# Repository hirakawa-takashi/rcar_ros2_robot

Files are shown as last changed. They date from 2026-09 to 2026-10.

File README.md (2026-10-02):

# rcar_ros2_robot (AI-CAR)

Raspberry Pi 5 + ROS2 Jazzy で動作するメカナム4輪自律走行ロボット AI-CAR のワークスペース。

## パッケージ

| パッケージ | 内容 |
|---|---|
| `ai_car_description` | URDF/Xacro モデル、表示用 Launch、RViz2 設定 |
| `ai_car_web` | FastAPI による Web ダッシュボード（テレメトリ表示・手動操作・システム監視） |

## ビルド

```bash
source /opt/ros/jazzy/setup.bash
cd ~/AI-CAR_ws
colcon build --symlink-install
source install/setup.bash
```

## 実行

ロボットモデルの表示（RViz2 は開発PC側で起動する想定）:

```bash
ros2 launch ai_car_description view_robot.launch.py          # robot_state_publisher + joint_state_publisher
ros2 launch ai_car_description view_robot.launch.py use_rviz:=true use_gui:=true
```

Web ダッシュボード:

```bash
ros2 launch ai_car_web dashboard.launch.py
# システム監視ノードを止める場合: use_system_monitor:=false
# ブラウザで http://<ラズパイのIP>:8080
```

起動時の自動起動（systemd）:

```bash
sudo ~/AI-CAR_ws/systemd/install_service.sh   # /etc/systemd/system/ai-car-dashboard.service を登録して起動
systemctl status ai-car-dashboard.service
sudo systemctl disable --now ai-car-dashboard.service   # 手動起動に戻す場合
```

サービスは `Restart=always`（5秒間隔）で、USB デバイスの認識を待つため起動を10秒遅延する。カメラ、LiDAR、IMU のノードは launch 側で `respawn` する。

CPU ファンの作動温度（既定 50/60/67.5/75℃）を前倒しして高温になりにくくする:

```bash
sudo cp ~/AI-CAR_ws/systemd/ai-car-fan.service /etc/systemd/system/
sudo systemctl enable --now ai-car-fan.service   # 45/50/55/62℃ を設定（起動ごとに再適用）
# 温度を変えたい場合は Environment=FAN_TRIP_TEMPS="..." をサービスに追加
```

設定値は `scripts/set_fan_curve.sh` が `thermal_zone0` の active トリップへ書き込む。ファン回転数と段階はダッシュボードの CPU カードに表示される。

## インターフェース

`dashboard_node`

- Publish: `/cmd_vel` (`geometry_msgs/Twist`)、`~/status` (`std_msgs/String`)
- Subscribe: `/scan` (`sensor_msgs/LaserScan`)、`/imu/data` (`sensor_msgs/Imu`)、`/odom` (`nav_msgs/Odometry`)、`/system_status` (`std_msgs/String`)、`/camera/image_raw/compressed` (`sensor_msgs/CompressedImage`)
- HTTP: `GET /`、`GET /api/status`、`GET /api/architecture`、`GET /api/dev_diary`、`POST /api/cmd_vel`、`POST /api/stop`、`GET /api/camera/snapshot`、`GET /api/camera/stream`（MJPEG）、WebSocket `/ws`
- パラメータ: `src/ai_car_web/config/dashboard.yaml`

操作コマンドは -1.0〜1.0 の正規化値で受け取り、`max_linear_speed` / `max_angular_speed` にスケールされる。
`cmd_timeout`（既定 0.7 秒）の間に新しい指令が来ない場合は自動的に停止する。
画面上部の「プロジェクト説明」ボタンから、`architecture.yaml` に基づく構成・安全機構・API・開発状況の7タブを確認できる。
`dashboard_node.api_token` または環境変数 `AI_CAR_API_TOKEN` を設定すると、POST `/api/*` に
`X-API-Token`（または Bearer）ヘッダーが必要になる。UI は `http://<PI_IP>:8080/?token=...` を
一度開くとトークンを localStorage に保存する。

`system_monitor_node`

- Publish: `/system_status` (`std_msgs/String`, JSON, 既定 1Hz)
- 内容: CPU 使用率（全体・コア別）・クロック・温度・ロードアベレージ、メモリ/Swap/ディスク、PMIC レール別の電圧・電流・電力と合計消費電力、スロットリング状態、AI HAT+ (Hailo-8) 検出状態
- パラメータ: `publish_rate` / `topic` / `enable_pmic` / `enable_hailo`
- 依存: `python3-psutil`、`vcgencmd`（Raspberry Pi）、`lspci`
- AI HAT+ の情報は `/dev/hailo0`（`hailo_pci` ドライバ）と `hailortcli` の有無に応じて段階的に表示する。ドライバ未導入時は PCIe 検出状態のみ。
- AI HAT+ の温度は HailoRT の C API `hailo_get_chip_temperature()` を ctypes で直接呼び出して取得する（ts0/ts1 の平均。`hailortcli` 4.24 に温度サブコマンドは無い）。
- NPU 使用率と消費電力は取得・表示しない（使用率は推論アプリを `HAILO_MONITOR=1` で起動している間だけ `hailortcli monitor` で参照できる）。
- AI HAT+ の電力は取得できない。`hailortcli measure-power` は `HAILO_UNSUPPORTED_OPCODE`（ボードに電流監視 DVM 非搭載）、`query_health_stats()` / `query_performance_stats()` は HAILO8 アーキテクチャ非対応。`hatctl` は Raspberry Pi OS / 他ベンダ向けで Ubuntu には存在せず、Hailo 専用の hwmon デバイスも無い。PMIC にも HAT 専用レールはなく（AI HAT+ は PCIe コネクタの 5V から給電）、単体の消費電力を測るには INA219/INA3221 などの外付け I2C 電流センサを配線に挿入する必要がある。
- ダッシュボードの AI HAT+ カードは温度（横バーグラフ）・状態・デバイス情報（アーキテクチャ / FW / ドライバ / PCIe アドレス）を表示する（NPU 使用率と消費電力は表示しない）。

## TM1637 4桁7セグメントLED のセットアップ（旧表示器）

`seg_display_node` は TM1637 モジュールを bit-bang 駆動し、`/display_state`
（`std_msgs/String`）へ現在の状態コードを publish する。

| TM1637 | Raspberry Pi 5 |
|---|---|
| VCC | 17（3V3） |
| GND | 20（GND） |
| CLK | 16（GPIO23） |
| DIO | 18（GPIO24） |

```bash
sudo apt install python3-libgpiod
sudo usermod -aG dialout super
# 再ログイン、またはサービスを再起動
```

GPIO チップは `pinctrl-rp1` のラベルから自動検出する（通常は `gpiochip4`）。
`dashboard.launch.py` の `use_seg_display`（既定 `true`）で起動し、
無効化する場合は `use_seg_display:=false` を指定する。

表示コード:

| コード | 意味 |
|---|---|
| `boot` | 起動後30秒以内でシステム状態未受信 |
| `rdy ` | 待機中 |
| `HAnd` | 手動操作中 |
| `ObSt` | 障害物停止 |
| `SLo ` | 減速 |
| `LoU ` | 低電圧 |
| `Err ` | システム状態未受信・タイムアウト |

## IMU (GY-BNO055) のセットアップ

`imu_node` は GY-BNO055（I2C バス1、ADRピンHigh、アドレス `0x29`）を読み取り、
`/imu/data`（`sensor_msgs/Imu`）へ publish する。I2C のアクセス権を追加して再ログインする。

```bash
sudo usermod -aG i2c super
# 再ログイン、またはサービスを再起動
i2cdetect -y 1    # 0x29 が表示されることを確認
```

`dashboard.launch.py` の `use_imu`（既定 `true`）で起動し、無効化する場合は
`use_imu:=false` を指定する。

## 落下防止センサー (VL53L1X ×2) のセットアップ

`cliff_node` は前後バンパーの Dovhmoh VL53L1X（真下から進行方向へ 45° 前傾）で床までの距離を測り、
段差の判定を `/cliff_status`（`std_msgs/String`、JSON、20 Hz）へ publish する。
測った距離が `cliff_distance_m`（既定 0.15 m。平らな床は約 0.095 m）を超えるか、床が見えない状態が
`confirm_count` 回続くと段差とする。`drive_mode_node` は前が段差なら前進、後ろが段差なら後退を止め、
自動運転は停止モードにする。

現在は未配線で、`cliff_node.wired: false` の間は I2C / GPIO に触らず「未配線」だけを配信する
（ダッシュボードの「落下防止センサー」カードに表示）。予定のピン割り付けは `gpio_pins.yaml`（配線色は未定）。

| 信号 | 前（0x30） | 後（0x31） |
| --- | --- | --- |
| VIN 3V3 | pin 1（IMU と分岐） | pin 17 |
| GND | pin 14 | pin 25 |
| SDA / SCL | pin 3 / 5（I2C バス 1 共有） | pin 3 / 5 |
| XSHUT | pin 11（GPIO17） | pin 13（GPIO27） |

VL53L1X の初期アドレス 0x29 は BNO055 と同じなので、`cliff_node` が XSHUT を 1 台ずつ上げ、
起動直後に 0x30 / 0x31 へ変える。モジュールの XSHUT は基板上で引き上げられていることが多く、
配線したのに `cliff_node` が動いていないと 0x29 で BNO055 とぶつかる。配線したら
`dashboard.yaml` の `cliff_node.wired` を `true` にしてサービスを再起動し、`i2cdetect -y 1` で
0x29（BNO055）・0x30・0x31・0x60（Motor HAT）が見えることを確かめる。
`dashboard.launch.py` の `use_cliff`（既定 `true`）で起動する。

## カメラ (IMX708 / Camera Module v3) のセットアップ（Ubuntu 24.04）

ダッシュボードは `/camera/image_raw/compressed` を購読し、`/api/camera/stream` で MJPEG 配信する。カメラノードは `camera_ros`（libcamera）を使用し、`dashboard.launch.py` の `use_camera`（既定 true）で起動する。

Ubuntu 24.04 の libcamera 0.7.2 は raspi カーネル 6.8 のメディアエンティティ名（`rp1-cfe-fe_image0` などアンダースコア形式）と一致せず `no cameras available` となるため、Raspberry Pi 版 libcamera / libpisp を `~/opt/rpicam` に導入する。

```bash
sudo apt install -y ros-jazzy-camera-ros
sudo apt install -y meson ninja-build pkg-config python3-jinja2 python3-yaml python3-ply \
  libyaml-dev libudev-dev libevent-dev libdrm-dev libjpeg-dev libtiff-dev libpng-dev \
  libssl-dev libgnutls28-dev libboost-dev libglib2.0-dev libgstreamer-plugins-base1.0-dev
# 開発用パッケージが解決できない場合は /etc/apt/sources.list.d/ubuntu.sources に noble-updates を追加する

git clone https://github.com/raspberrypi/libpisp.git ~/libpisp
cd ~/libpisp && meson setup build --prefix=$HOME/opt/rpicam && ninja -C build install

git clone https://github.com/raspberrypi/libcamera.git ~/libcamera
cd ~/libcamera
PKG_CONFIG_PATH=$HOME/opt/rpicam/lib/$(uname -m)-linux-gnu/pkgconfig \
  meson setup build --prefix=$HOME/opt/rpicam \
  -Dpipelines=rpi/pisp,rpi/vc4 -Dipas=rpi/pisp,rpi/vc4 \
  -Dv4l2=false -Dgstreamer=disabled -Dtest=false -Dlc-compliance=disabled \
  -Dcam=enabled -Dqcam=disabled -Ddocumentation=disabled -Dpycamera=disabled \
  -Dcpp_args=-I$HOME/opt/rpicam/include
ninja -C build install

# 確認
LD_LIBRARY_PATH=$HOME/opt/rpicam/lib/$(uname -m)-linux-gnu $HOME/opt/rpicam/bin/cam -l
```

`dashboard.launch.py` は `~/opt/rpicam` があればカメラノードの `LD_LIBRARY_PATH` に自動で追加する（apt 版 `camera_ros` をそのまま利用できる）。

## AI HAT+ (Hailo-8) のセットアップ（Ubuntu 24.04）

`hailo-all` は Raspberry Pi OS 専用のため Ubuntu では使えない。ドライバと HailoRT をソースから導入する。

```bash
sudo apt-get install -y linux-headers-$(uname -r) build-essential cmake git
git clone https://github.com/hailo-ai/hailort-drivers.git
cd hailort-drivers && git checkout v4.24.0          # v5 系は Hailo-10 専用で Hailo-8 (1e60:2864) 非対応
cd linux/pcie && make all && sudo make install
cd ~/hailort-drivers && ./download_firmware.sh
sudo mkdir -p /lib/firmware/hailo
sudo cp hailo8_fw*.bin /lib/firmware/hailo/hailo8_fw.bin
sudo cp linux/pcie/51-hailo-udev.rules /etc/udev/rules.d/
sudo depmod -a && sudo udevadm control --reload-rules && sudo udevadm trigger
sudo reboot

# 再起動後に HailoRT（ドライバと同じ 4.24.0）をビルド
git clone --depth 1 --branch v4.24.0 https://github.com/hailo-ai/hailort.git
cd hailort && cmake -S . -B build -DCMAKE_BUILD_TYPE=Release -DHAILO_BUILD_PYBIND=OFF
cmake --build build --config release -j2
sudo cmake --install build && sudo ldconfig
hailortcli fw-control identify
```

### Python バインディング（`perception_node` の推論に必要）

```bash
cmake -S ~/hailort/hailort/libhailort/bindings/python/src -B ~/pyhailort_build \
      -DPYBIND11_PYTHON_VERSION=3.12 -DCMAKE_BUILD_TYPE=Release
cmake --build ~/pyhailort_build -j4
cp ~/pyhailort_build/_pyhailort*.so \
   ~/hailort/hailort/libhailort/bindings/python/platform/hailo_platform/pyhailort/
pip3 install --user --break-system-packages \
   ~/hailort/hailort/libhailort/bindings/python/platform
python3 -c "from hailo_platform import VDevice; print('ok')"
```

### 物体検出モデル

```bash
mkdir -p ~/AI-CAR_ws/models
curl -L -o ~/AI-CAR_ws/models/yolov8m.hef \
  https://hailo-model-zoo.s3.eu-west-2.amazonaws.com/ModelZoo/Compiled/v2.16.0/hailo8/yolov8m.hef
```

標準設定は YOLOv8m で、パスは `config/dashboard.yaml` の `perception_node.hef_path` で指定する。YOLOv8s / YOLOv8n を使う場合は `hef_path` をそれぞれ `~/AI-CAR_ws/models/yolov8s.hef` / `~/AI-CAR_ws/models/yolov8n.hef` に変更する（未設定なら LiDAR 判定のみで動作）。

## 依存

```bash
sudo apt install -y ros-jazzy-robot-state-publisher ros-jazzy-joint-state-publisher ros-jazzy-xacro
# SLAM（地図と自己位置、use_slam:=true）を使うとき
# 地図の保存（/slam_toolbox/save_map）は nav2_map_server の map_saver_cli を使う
sudo apt install -y ros-jazzy-slam-toolbox ros-jazzy-nav2-map-server
sudo apt install -y python3-psutil
pip3 install fastapi uvicorn
# WebSocket 配信（未導入なら /api/status の 250ms ポーリングへ自動フォールバック）。
# apt の python3-websockets 10.4 は uvicorn が要求する API を持たないため使わない。
pip3 install --user --break-system-packages "websockets>=13"
```

映像の滑らかさは `config/dashboard.yaml` で調整する。既定は `camera` の `width: 960` /
`height: 540` / `jpeg_quality: 80`（`FrameDurationLimits` により約 30fps。以前の 1280×720 は camera_node の CPU が約 50% になるため縮小）、`dashboard_node.camera_stream_rate: 30.0`、
`perception_node.inference_rate: 15.0`、`dashboard_node.telemetry_rate: 10.0`、`dashboard_node.scan_max_points: 720`、
`autonomy_node.publish_rate: 10.0`、`joy_teleop_node.publish_rate: 10.0`、`imu_node.publish_rate: 20.0` に設定している。
帯域や CPU が厳しい場合は解像度か `jpeg_quality` を下げる。

## ドキュメント

- 開発方針: `PROJECT_RULES.md`
- 実装状況: `PROJECT_STATUS.md`
- ハードウェア構成: `HARDWARE_BOM.md`
- 変更履歴: `CHANGELOG.md`

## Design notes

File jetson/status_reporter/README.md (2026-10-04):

# Jetson の状態を AI-CAR のダッシュボードに出す

Jetson Orin Nano Super の温度・使用率・メモリ・電力・AI の部品（声の AI・物体検出）・
セキュリティ更新の状況を、1 秒ごとに AI-CAR へ送ります。ダッシュボードの
「Jetson Orin Nano Super」カードに出ます。

```
Jetson  /proc・/sys・systemctl・HTTP（whisper 8178 / Ollama 11434 / Kokoro 8880）
        → POST /api/jetson/status（API トークン）→ AI-CAR の dashboard_node → /api/status の jetson_host
```

5 秒以上届かないと、カードは「未接続」になります。表示だけで、AI-CAR の速度には使いません。

## 送るもの
- 温度（CPU・GPU・Tj）、CPU / GPU の使用率とクロック、ファン
- メモリ・スワップ・ディスク、ボード全体の入力電圧と消費電力（INA3221 の `VDD_IN`）、電源モード（`nvpmodel -q`）
- AI の部品が動いているか: `whisper-server`（声→文字。`whisper-server.service` の `-m` から仕組みの名前 `stt_engine`、例: whisper.cpp small（GPU））、`ollama`（会話の AI、読み込み中のモデルと、その大きさ・GPU に載っている量）、
  Kokoro（文字→声、Docker。`/openapi.json` の題名と版から `tts_engine`、例: Kokoro TTS 1.0.0）、`jetson-owl`（NanoOWL の物体検出）
- 更新: 残りの更新とセキュリティ更新の数（`apt-check`、重いので 1 時間に 1 回と、ボタンの更新のあと）、再起動が必要か、
  最後に自動更新（unattended-upgrades）が動いた時刻。残りの更新の数には、NVIDIA の部品（JetPack: `nvidia-`・`cuda-`・
  `libcudnn`・`libnvinfer`・`tensorrt`）を入れない（その数は `updates_held`）。ボタンの更新が動いているかと、前回の結果
- IP アドレス（Tailscale・Wi-Fi など。lo・Docker・USB の `l4tbr0` は出さない。30 秒ごとに調べる）、再起動ボタンが使えるか（`sudo -n -l`）

## ファイル
- `jetson_status.py`: 本体。標準ライブラリだけで動く（Jetson の `/usr/bin/python3`）
- `jetson-status.service`: Jetson の systemd サービス（ユーザー `jetson` で動かす）
- `jetson-upgrade.sh`・`jetson-upgrade.service`・`jetson-upgrade.sudoers`: ダッシュボードの「Jetson を更新」ボタン用

## 入れ方（Jetson、JetPack 6.2 / L4T 36.4.3 で確認）
```bash
# このフォルダを ~/status_reporter にコピーする
sudo install -m 600 /dev/null /etc/jetson-status.env
sudoedit /etc/jetson-status.env   # 次の 2 行を書く（jetson-owl と同じ値）
#   AI_CAR_URL=http://100.70.35.31:8080
#   AI_CAR_API_TOKEN=<AI-CAR の dashboard_node の API トークン>
sudo cp ~/status_reporter/jetson-status.service /etc/systemd/system/
sudo systemctl daemon-reload
sudo systemctl enable --now jetson-status.service
journalctl -u jetson-status -f
```

## ダッシュボードの「再起動」「電源を切る」ボタン
Jetson カードの「Jetson を再起動」を押すと、AI-CAR は次に状態が届いたときの返事に `"reboot": true` を入れます。
`jetson_status.py` はそれを見て `sudo -n systemctl reboot` を実行します。「Jetson の電源を切る」は `"poweroff": true` で、`sudo -n systemctl poweroff` を実行します（入れ直すのは本体の電源ボタンか電源のつなぎ直し）。パスワードなしで再起動と電源を切ることだけを許す設定が要ります:
```bash
sudo visudo -cf ~/status_reporter/jetson-reboot.sudoers
sudo install -m 440 ~/status_reporter/jetson-reboot.sudoers /etc/sudoers.d/jetson-reboot
```
入っていないときはボタンを押しても「jetson-reboot.sudoers が入っていません」（電源は「… に poweroff が入っていません」）と出て、何もしません。

## ダッシュボードの「Jetson を更新」ボタン
自動の更新（unattended-upgrades）はセキュリティ更新だけを入れます。ほかの更新は、ボタンを押したときだけ入れます。
押すと、AI-CAR は次の返事に `"upgrade": true` を入れ、`jetson_status.py` が `sudo -n systemctl start --no-block jetson-upgrade.service` を実行します。
`jetson-upgrade.sh`（root）は `apt-get update` のあと、NVIDIA の部品を除いて `apt-get install --only-upgrade` します。
先に試しに動かして（`apt-get -s`）、NVIDIA の部品が変わるか、消える部品があるときは、更新せずに失敗にします。
動いているあいだはカードに「更新中 45 %」のように進み具合が出ます（`jetson-upgrade.sh` が `/run/jetson-upgrade.progress` に書く。ダウンロードが 0〜30 %、インストールが 30〜100 %）。終わると「前回は成功」か「前回は失敗」と出ます。記録は `journalctl -u jetson-upgrade` で見られます。
```bash
sudo install -m 755 ~/status_reporter/jetson-upgrade.sh /usr/local/sbin/jetson-upgrade
sudo cp ~/status_reporter/jetson-upgrade.service /etc/systemd/system/
sudo systemctl daemon-reload
sudo visudo -cf ~/status_reporter/jetson-upgrade.sudoers
sudo install -m 440 ~/status_reporter/jetson-upgrade.sudoers /etc/sudoers.d/jetson-upgrade
sudo systemctl restart jetson-status.service
```

1 回だけ集めて表示するとき（AI-CAR には送らない）:
```bash
python3 ~/status_reporter/jetson_status.py --once
```

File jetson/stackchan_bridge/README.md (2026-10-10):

# スタックちゃんを Jetson の会話の AI につなぐ（stackchan_bridge）

M5Stack の純正ファームウェア（StackChan 1.5.1、中の会話は XiaoZhi）の AI Agent を、
ネットの向こうの XiaoZhi のサーバーではなく、家の Jetson の会話の AI につなぎます。
表情・首振り・画面・タッチは純正のままです。AI-CAR の走行・安全停止には何も送りません。

```
スタックちゃん ──HTTP :8003 /xiaozhi/ota/──▶ stackchan_bridge（WebSocket の行き先だけ返す。新しい版は返さない）
             ──WebSocket :8000 /xiaozhi/v1/─▶ 声（Opus 16 kHz）→ 音の大きさで区切る
                                              → whisper-server :8178（声→文字）
                                              → Ollama :11434 qwen2.5:3b（返事、1 文ずつ）
                                              → Kokoro :8880 jf_alpha + sox pitch 300・norm -1 dB（文字→声）
             ◀── Opus 24 kHz・60 ms ──────────┘  stt / llm（表情）/ tts の JSON も送る
```

- 2026/10 の実機: 聞き取り 約 0.3〜0.7 秒、話し終わってから声が出るまで 約 1.6〜2.8 秒。メモリ 約 37 MB
- 返事の声: Kokoro のままだといちばん大きい所が上限の約 4 割（-7 dB）で小さかったので、文ごとに -1 dB にそろえる（`--peak-db`）
- 声の区切り: まわりの音の 3 倍（最低 RMS 300）より大きいと話し始め、0.8 秒静かなら話し終わり（`--ratio`・`--min-level`・`--end-silence`）。
  「(音楽)」のような文字だけの聞き取りは捨てる
- whisper の聞き取り: 毎回 `no_context=true` を送る（前の聞き取りを手がかりにすると、一度まちがえたあと、どの声も「(スタックちゃん)」のような決まった言葉になる）。5 分ごとに Kokoro の「スタックちゃん」（呼びかけが出るはず）と「今日の天気はどうですか」（出ないはず）を聞き取らせ、ちがえば `pkill -KILL -x whisper-server` で止める（`Restart=on-failure` で起動し直る）
- 呼びかけ待ちの首ふり: スタックちゃんはいつも聞いている（listening）ので、純正の待ち受けの首ふりは動かない。bridge が 5〜10 秒ごとに `self.robot.set_head_angles` で首を動かす（純正の 4 種類をまねる）。動かしてから 1.2 秒は新しい声の区切りを始めない。居眠り中・会話中・撮影中は動かさない
- 会話は 3 往復まで覚える（WebSocket が切れると忘れる）。今の日時をシステムの指示に入れる
- `GET :8003/status`: つながり（`connected`）・今の様子（`state`: `listening` / `thinking` / `speaking` / `idle`）・最後の会話（`last`: 聞き取り・返事・かかった秒）・本体（`device`: MAC・IP・版）・会話の数（`turns`）を JSON で返す。AI-CAR のダッシュボードのスタックちゃんのカードが `GET /api/stackchan/status` 経由で 2 秒ごとに取る
- カメラ: つながると MCP の `initialize` で写真の送り先（`http://<Jetson>:8003/vision`）を教え、`tools/list` に `self.camera.take_photo` があれば `camera: true`。`POST :8003/photo` でその道具を呼ぶと、スタックちゃんが 320×240 の JPEG（約 12 KB）を `/vision` へ送り、`GET :8003/photo.jpg` でいちばん新しい 1 枚を返す（`photo_at` は撮った時刻）。ファイルには保存しない。撮るたびにスタックちゃんでシャッターの音が鳴る。ダッシュボードの「写真を撮る」が `POST /api/stackchan/photo` 経由で呼ぶ
- 認証はしない（`token` は空）。家の LAN・Tailscale の中だけで使う

## Jetson に入れる

```bash
mkdir -p ~/stackchan_bridge
cp stackchan_bridge.py ~/stackchan_bridge/
pip3 install --user websockets==13.1 opuslib==3.0.1   # libopus0 と sox も要る
sudo install -m 644 jetson-stackchan.service /etc/systemd/system/
sudo systemctl daemon-reload
sudo systemctl enable --now jetson-stackchan.service
journalctl -u jetson-stackchan -f    # 聞き取り・返事・かかった秒数が出る
```

## パソコンで聞き取りと返事（WSL の Ubuntu、RTX 4080 SUPER）

パソコンが動いているあいだは、聞き取り（whisper large-v3）と返事（Ollama qwen2.5:14b）をパソコンでする。
文字→声（Kokoro）・呼びかけの見分け・カメラ・見守りは Jetson のまま。

- bridge が 10 秒ごとに `http://<パソコン>:8178/` と `:11434/api/tags` を見て（2 秒で時間切れ）、どちらも返事をして
  `--pc-model` があれば、モデルを読み込ませてからパソコンを使う。聞き取り（10 秒）・返事（10 秒）でつながらなければ、
  その回から Jetson（whisper small・qwen2.5:3b）にもどす。返事の途中で切れたときは、その返事はやめる
- 行き先は `--pc-host`（既定は環境変数 `AI_PC_HOST`、なければ Tailscale の taka3-wsl `100.86.172.21`）。空でパソコンを使わない
- 使っているほうは `GET :8003/status` の `engines` に出る（「（パソコン）」がつく）。`backend` は `want`（選んだ所 `jetson` / `pc`）・`active`（今使っている所）・`error`（パソコンにつながらない理由）
- パソコンの状態（ダッシュボードでパソコンを選んだときの Jetson のカード）: `pc/pc_status.py` を `/home/super/ai/` に置き、`pc/pc-status.service` を入れる（`/etc/pc-status.env` に `AI_CAR_API_TOKEN=...`）。1 秒ごとに `POST /api/mypc/status`（jetson-status と同じ形 ＋ `gpu_name`・`gpu_driver`）
- 声でも切りかえる（ローカルのときの会話モードで）: 「ミニコン / ジェットソン」→ `jetson`、「パソコン / PC」のあとに「にして」など（ネット / ローカルと同じ言い方）。ネット / ローカルとは別で、どちらの組み合わせでも使える。ネットのあいだの言葉は XiaoZhi が聞くので、先に「ローカルにして」
- 切り替え: `POST :8003/backend?to=jetson|pc`（ダッシュボードの Jetson のカードの 1 行目のミニコン / パソコンボタンが `POST /api/stackchan/backend` 経由で呼ぶ）。`backend.txt` に書いて、起動し直してもそのまま。`jetson` ならパソコンを見ない。`pc` にするとすぐパソコンを見て、動いていれば使う（つながらないあいだは Jetson）
- whisper の見回り（5 分ごと）は Jetson の whisper-server だけを試す
- 文字→声: パソコンを使っているあいだは、パソコンの VOICEVOX ENGINE（CPU、`:50021`）の `--pc-speaker`（既定 3 = ずんだもん ノーマル）。高さはそのまま（Kokoro だけ `--pitch` で上げる）。パソコンを見るときに `POST /initialize_speaker` で読み込ませ、だめならその回から Kokoro。2026/10 の実機（ミニコンから）: 「こんにちは。」0.27 秒、26 文字の文 0.75 秒。家の中だけで使う（外に出すときは「VOICEVOX:ずんだもん」と書く決まり）
- 2026/10/10 の実機（Jetson から同じ声 4 つ）: 聞き取り Jetson 0.53〜0.74 秒 → パソコン 0.29〜0.44 秒（Tailscale の中継込み）。
  返事は Jetson qwen2.5:3b 15〜17 文字片/秒 → パソコン qwen2.5:14b 約 62 文字片/秒（読み込みは最初の 1 回 約 31 秒）。
  GPU のメモリは whisper large-v3 と 14b で 16 GB のうち約 13.9 GB

パソコンに入れる（WSL 3.0.1 の Ubuntu 26.04、ユーザー `super`、Tailscale と openssh-server 入り）:

```bash
sudo apt install -y build-essential cmake git
# CUDA（WSL 用。Windows の NVIDIA ドライバーはそのまま）
curl -fsSLO https://developer.download.nvidia.com/compute/cuda/repos/wsl-ubuntu/x86_64/cuda-keyring_1.1-1_all.deb
sudo dpkg -i cuda-keyring_1.1-1_all.deb && sudo apt update && sudo apt install -y cuda-toolkit-13-3
mkdir -p ~/ai && cd ~/ai && git clone --depth 1 https://github.com/ggml-org/whisper.cpp && cd whisper.cpp
curl -fL -o models/ggml-large-v3.bin https://huggingface.co/ggerganov/whisper.cpp/resolve/main/ggml-large-v3.bin
PATH=/usr/local/cuda/bin:$PATH cmake -B build -DGGML_CUDA=1 -DCMAKE_CUDA_ARCHITECTURES=89 -DCMAKE_BUILD_TYPE=Release
cmake --build build -j 24 --target whisper-server
sudo install -m 644 pc/whisper-server.service /etc/systemd/system/   # このフォルダの pc/
curl -fsSL https://ollama.com/install.sh | sh
sudo install -D -m 644 pc/ollama-override.conf /etc/systemd/system/ollama.service.d/override.conf
sudo systemctl daemon-reload && sudo systemctl enable --now whisper-server && sudo systemctl restart ollama
ollama pull qwen2.5:14b
# VOICEVOX ENGINE 0.25.2（linux-cpu-x64）を https://github.com/VOICEVOX/voicevox_engine/releases から ~/ai/voicevox に展開
sudo install -m 644 pc/voicevox.service /etc/systemd/system/ && sudo systemctl daemon-reload && sudo systemctl enable --now voicevox
# CPU 温度: Windows に LibreHardwareMonitor 0.9.6 を置き、管理者で 1 回起動して Options の「Run On Windows Startup」「Start Minimized」「Remote Web Server → Run」を入れる
#   （設定ファイルでは runWebServerMenuItem=true。pc_status.py は Windows の PowerShell から http://localhost:8085/data.json の CPU Package を読む）
```

WSL は PowerShell の画面を閉じるとしばらくして止まるので、`pc/wsl-ubuntu-keepalive.vbs` を Windows の
スタートアップ（`%APPDATA%\Microsoft\Windows\Start Menu\Programs\Startup`）に置き、ログインしたら
`wsl.exe -d Ubuntu --exec /bin/sleep infinity` を見えないまま動かしておく（消せば元にもどる）。

## スタックちゃんのファームウェア

公式 https://github.com/m5stack/StackChan の `firmware`（ESP-IDF v5.5.4）に、ここの 4 つを足してビルドします。

| ファイル | 置く所 | 中身 |
| --- | --- | --- |
| `firmware/sdkconfig.defaults.local` | `StackChan/firmware/` | `CONFIG_OTA_URL` を Jetson（`http://192.168.11.23:8003/xiaozhi/ota/`）にする |
| `firmware/xiaozhi-no-auto-upgrade.patch` | `StackChan/firmware/xiaozhi-esp32/` で `git apply` | AI Agent を開くたびの自動更新（`UpgradeFirmware`）をやめ、ログだけ出す（純正の版にもどらないように） |
| `firmware/xiaozhi-auto-reopen.patch` | `StackChan/firmware/xiaozhi-esp32/` で `git apply` | 会話が切れたら（画面をさわって止めたとき以外）、自分でつなぎ直す（3 秒後、だめなら 6・12…最大 60 秒ごと。つなぎ直しの失敗ではエラーの音を出さない）。AI Agent を開いたときも 2 秒後に自分でつなぐ（下の「呼びかけ」） |
| `firmware/stackchan-camera-stream.patch` | `StackChan/firmware/` で `git apply` | カメラの映像を OTA と同じ所の `/camera/frame` へ送り続ける（下の「カメラの映像」） |
| `firmware/stackchan-face-color.patch` | `StackChan/firmware/` で `git apply` | 顔（目と口）の色を変える MCP の道具 `self.robot.set_face_color`（`color`: 0xRRGGBB）。user only なので、ネットの AI からは見えない（下の「ネットとローカルの切り替え」） |
| `firmware/xiaozhi-fallback-pc.patch` | `StackChan/firmware/xiaozhi-esp32/` で `git apply`（auto-reopen のあと） | ミニコンが答えないとき、パソコン（`AICAR_FALLBACK_HOST` 192.168.11.7、同じ 8000・8003 番）につなぐ。WebSocket は毎回ミニコンを先に試し、だめならパソコン。起動のときの OTA も、失敗するたびにミニコンとパソコンを入れかえて聞く（下の「ミニコンが落ちたとき」） |
| `firmware/stackchan-camera-follow-server.patch` | `StackChan/firmware/` で `git apply`（camera-stream のあと） | カメラの映像・撮影の写真を、今つないでいる受け口（ミニコンかパソコン）へ送る |
| `firmware/stackchan-countdown-shot.patch` | `StackChan/firmware/` で `git apply`（camera-stream のあと） | 「撮影して」の MCP の道具 `self.camera.countdown_photo`（`seconds`: 1〜9）。正面を向き、画面にカメラと数字を出して数え、撮って `/camera/shot` へ送る（下の「撮影と名前の登録」） |

```bash
cd StackChan/firmware
python3 ./fetch_repos.py                 # 依存の取得と公式のパッチ
cp <このフォルダ>/firmware/sdkconfig.defaults.local .
git -C xiaozhi-esp32 apply <このフォルダ>/firmware/xiaozhi-no-auto-upgrade.patch
git -C xiaozhi-esp32 apply <このフォルダ>/firmware/xiaozhi-auto-reopen.patch
git apply <このフォルダ>/firmware/stackchan-camera-stream.patch
git apply <このフォルダ>/firmware/stackchan-face-color.patch
git apply <このフォルダ>/firmware/stackchan-countdown-shot.patch
git -C xiaozhi-esp32 apply <このフォルダ>/firmware/xiaozhi-fallback-pc.patch
git apply <このフォルダ>/firmware/stackchan-camera-follow-server.patch
. ~/esp/esp-idf-v5.5.4/export.sh
idf.py build
# Jetson の USB-A につなぐと /dev/ttyACM0。Wi-Fi の設定（NVS）は消えない
python3 esptool.py --chip esp32s3 -p /dev/ttyACM0 -b 921600 write_flash $(cat build/flash_args)
```

- 書き込むのは ota_0（0x20000）・assets（0xa00000）・otadata（0xd000）など。NVS（0x9000）の Wi-Fi の設定と、スマホのアプリの登録はそのまま
- Jetson の IP アドレスが変わるとつながらない。ルーターで固定する（2026/10: Jetson 192.168.11.23、スタックちゃん 192.168.11.8）
- スマホのアプリで変える AI の設定（声・性格）は使わなくなる。声の大きさは本体の設定の「Volume」（0〜100、最初は 70）でも変えられる

## ミニコンが落ちたとき（パソコンの控え）

パソコンでも同じ bridge を `--primary-url` つきで動かしておきます（`pc/pc-stackchan.service`、聞き取り・返事・声は
パソコンの whisper large-v3・qwen2.5:14b・VOICEVOX）。

```
スタックちゃん → ws://192.168.11.23:8000（ミニコン）… だめなら → ws://192.168.11.7:8000（Windows）
                 → portproxy → WSL の 127.0.0.1:8000（パソコンの bridge）
```

- Windows（管理者で 1 回）: `pc/stackchan-portproxy.ps1`。LAN の `192.168.11.7:8000/8003` を WSL へ通し、ファイアウォールで
  同じ LAN（LocalSubnet）からだけ入れる。パソコンの IP アドレスはルーターで固定する
- パソコンの bridge はミニコンの `GET /status` を 10 秒ごとに見る。動いていてスタックちゃんがつながっていなければ、
  ネット / ローカルと声の選択をまねる。スタックちゃんがこちらにつながっていて、ミニコンが 3 回続けて（約 30 秒）動いていて、
  呼びかけ待ち（会話中・撮影中・ネットの会話中でない）なら、こちらから切る → スタックちゃんは 3 秒後にミニコンへつなぎ直す
- パソコンの bridge では「ミニコンにして」・`POST /backend?to=jetson` は使えない（「ミニコンが止まっているあいだは、パソコンで話します。」）。
  見守り（face_id）・Kokoro・whisper の見回りは使わない。VOICEVOX が止まると声が出ない
- ダッシュボードは、ミニコンが未接続か bridge が答えないとき、パソコンの bridge（Tailscale の :8003）からスタックちゃんの様子を出す
- ミニコンが止まってから、パソコンで話せるまで: 会話が切れて 3 秒後につなぎ直し（ミニコンへの接続が失敗してから）。
  起動のときにミニコンが止まっていれば、OTA の 1 回目の失敗から 10 秒後にパソコンに聞く

```bash
# パソコン（WSL）
sudo apt install -y python3-websockets python3-numpy python3-opencv python3-opuslib sox
mkdir -p ~/ai/stackchan_bridge && cp stackchan_bridge.py ~/ai/stackchan_bridge/
sudo install -m 644 pc/pc-stackchan.service /etc/systemd/system/ && sudo systemctl daemon-reload && sudo systemctl enable --now pc-stackchan
```

## カメラの映像

`stackchan-camera-stream.patch` を入れると、AI Agent の間、スタックちゃんが会話とは別に（画面をさわらなくても）
`http://<OTA と同じ所>/camera/frame` に聞きに来ます。

```
スタックちゃん: GET  /camera/frame          → bridge: 「1」（ダッシュボードが 10 秒以内に見に来た）/「0」
                「1」なら JPEG（320×240、品質 30、シャッターの音なし）を POST /camera/frame、返事が「1」の間くり返す
                「0」なら 2 秒ごとに GET だけ（撮らない）、つながらないと 5 秒ごと
ダッシュボード: GET /api/stackchan/frame.jpg（0.25 秒ごと、ページを見ている間だけ）→ bridge GET /camera/frame.jpg
```

- 映像はいちばん新しい 1 コマだけをメモリに置きます（保存しない）。3 秒より古いと 404
- `/status` の `stream_at`（スタックちゃんが最後に聞きに来た時刻）・`frame_at`・`fps` をダッシュボードが出します。
  `stream_at` がないときは、前のとおり「写真を撮る」（MCP の `self.camera.take_photo`）だけ
- 「写真を撮る」と映像は同じカメラを使うので、ファームウェアの中で順番に使います（`frame_mutex_`）

## 撮影と名前の登録

```
「撮影して」「写真を撮って」（ローカルは whisper、ネットは XiaoZhi の stt を bridge が見る）
  → bridge「撮影します。こっちを向いてね。」→ MCP self.camera.countdown_photo {seconds: 5}
  → スタックちゃん: 首を正面（yaw 0）へ → bridge が self.robot.set_head_angles で上（pitch 30 度、--shot-pitch。数えているあいだ 1 秒ごとに送り直す）へ → 画面にカメラの映像と右上に 5〜1 の数字（1 秒ごとにピッ）
  → 0 でシャッターの音 → 撮った写真を 6 秒画面に出す → JPEG（320×240、品質 80）を POST /camera/shot
  → bridge: face_id の /api/face/recognize で顔を見る →「撮れたよ。ダッシュボードで名前を登録してね。」など
ダッシュボード: 写真の下の「名前」→「名前を登録」→ POST /api/stackchan/enroll?name= → bridge POST /enroll?name=
  → face_id の /api/face/enroll（顔が 1 つ・幅 60 px 以上・ほかの人と近すぎない）
```

- 数えるのと撮るのは、ファームウェアの映像の送り係（`cam_frame` の task）がします。MCP の返事はすぐ返り、
  会話の動き（main の task）は止めません。bridge は写真が `/camera/shot` に届くまで最大 20 秒待ちます
- ネットのときも同じです。そのときは XiaoZhi に `abort` を送り、撮り終わるまで XiaoZhi の声と文字はスタックちゃんへ流しません
- face_id の API トークンは、`jetson-stackchan.service` の `EnvironmentFile=/etc/jetson-status.env` の
  `AI_CAR_API_TOKEN` を使います。face_id の場所は `FACE_ID_URL`（既定 `http://127.0.0.1:8090`）
- 顔の見分けは、あいさつや表示だけに使います。鍵・走行・安全停止には使いません
- `/status` の `shot_tool`（ファームウェアに道具がある）・`shooting`（数えている）・`shot`（`faces`・`name`・`error`）

## 見守りとあいさつ

```
スタックちゃんの映像の送り係が 2 秒ごとに GET /camera/frame で聞きに来る
  → bridge が見守りの時刻なら「1」→ 次に 1 枚（320×240）を POST /camera/frame
  → bridge: face_id の /api/face/recognize → 登録した人がいて、30 分あいさつしていなければ
  → 「○○さん、こんにちは！」（4〜10 時 おはよう、17 時から こんばんは）
```

- 間隔は `--watch-interval`（既定 2 秒、0 で見守りをしない）。映像の 1 枚は約 4 KB で、2〜3 秒に 1 枚です。ファームウェアの書き換えはいりません
- あいさつは、スタックちゃんが会話でつながっているときだけです（つながっていないと声を出せません）。会話・撮影・ネットとの切り替えの最中もしません
- 撮影や名前の登録をした人は、そのときあいさつしたものとして数えます
- `/status` の `watch_on`・`watch`（`at`・`faces`・`names`・`error`）・`greet`（`at`・`names`）

## 呼びかけ（「スタックちゃん」、ネットもローカルも）

スタックちゃんの中の呼びかけ（WakeNet の「Hi, Stack Chan」）は英語の読み上げ声の見本と比べるので、日本語の発音ではほとんど反応しません。
そこで、ネットのときもローカルのときも Jetson が日本語の「スタックちゃん」を聞き分けます。ファームウェアの書き換えはいりません。

```
つながる（ランプが緑）→ 「呼びかけ待ち」（/status の state が waiting）。名前なしの声には返事をしない
  → 声は whisper で文字にして、「スタックちゃん」が入っているときだけ会話モードにする
     「スタックちゃん」だけ → 「はい、なあに？」（Jetson の声）→ 会話モード
     「スタックちゃん、今日は何曜日？」→ そのまま返事して会話モード
  → 会話モードのあいだは名前なしで話せる
  → 最後に話してから 30 秒（--awake-seconds）だまっていると「じゃあ、またね。」（Jetson の声）→ 呼びかけ待ちにもどる
```

- ネットのとき: 呼びかけ待ちのあいだは、声を XiaoZhi へ送らない（Jetson で文字にするだけ）。「スタックちゃん、〜」と呼ばれたら、
  その声を Opus 16 kHz にしなおして XiaoZhi へ送り、そのあとの声はそのまま流す。会話モードの時間は、XiaoZhi の聞き取り（stt）と
  話し終わり（tts stop）でのばす。XiaoZhi が話しているあいだ（歌など）は「またね」を言わない
- ネットの会話（XiaoZhi）は、呼ばれたときに開き、「じゃあ、またね。」のときに閉じる。XiaoZhi は 1 分ほど声が届かないと、自分で
  「お疲れさん！…じゃあな！」と言って切るので、呼びかけ待ちのあいだは開いておかない（呼ばれてから話し始めるまで 約 1 秒おそくなる）
- テレビの声で起きないように、呼びかけは「文の頭で名前を呼んだ」ときだけにする（`is_call`）。whisper の音の注釈（「(音楽)」「(スタックちゃん)」）がある声、名前の前が 4 文字以上ある声（「段ボール箱、スタックちゃん」）、名前のすぐあとが「の・は・が」など（「スタックちゃんの研究」）の声、whisper-server の `--prompt` をそのまま返した声（「スタックちゃん、AI-CAR。」）は呼びかけにしない。「ねえ、スタックちゃん」「スタックちゃん、〜」は呼びかけになる
- 聞き分ける言葉は `--wake-words`（正規表現。whisper の書き方のゆれ「スダックちゃん」「スタッチャン」「Stack-chan」なども入れてある）。空にすると呼びかけ待ちにせず、今までどおり何にでも返事をする
- スタックちゃんは、Jetson から 120 秒何も届かないと会話が切れたとみなすので、60 秒ごとに `{"type": "ping"}` を送る（スタックちゃんは知らない種類として記録に 1 行出すだけ）
- 呼びかけ待ちのあいだも、聞こえた声は whisper で文字にします（1 回 約 0.4〜0.5 秒）。テレビの声なども文字にするので、Jetson が少し働きます。返事はしません
- 「ネットにして」「撮影して」も、呼びかけ待ちのときは「スタックちゃん、ネットにして」のように名前を付けて言います
- 呼びかけは、スタックちゃんが Jetson につながっている（ランプが緑）ときだけ聞こえます。ランプが消えている（待ち受け）ときは声を送らないので、`xiaozhi-auto-reopen.patch` で、会話が切れたら自分でつなぎ直します（画面をさわって止めたときはつなぎ直さない）。AI Agent を開いたときも、さわらなくてもつながります。つなぎ直したときも、呼びかけ待ちから始まります
- あいさつ（見守り）・切り替えのお知らせ・画面をさわって止めたあとも、30 秒は名前なしで返事できます（そのあと「じゃあ、またね。」）

## 居眠りと画面の明るさ

- 居眠り: 「じゃあ、またね。」（つながった直後は、つながったとき）から 30 秒（`--doze-seconds`、0 で居眠りしない）たつと、
  居眠りの顔（`{"type": "llm", "emotion": "sleepy"}`、画面に Zzz）にして、首をホーム（正面・水平、MCP `self.robot.set_head_angles` の yaw 0・pitch 0）にもどす。
  呼ばれたり、あいさつしたりするときは、ふつうの顔（`neutral`）にもどす。`/status` の `dozing`
- 画面の明るさ: 見守りの映像（2〜3 秒に 1 枚）の明るさ（0〜255 の平均）の 1 分の中央値で、60 秒ごとに画面の明るさ（MCP `self.screen.set_brightness`、0〜100）を決める。
  30 未満（夜の暗い部屋）→ 10、30〜70 → 35、70 以上 → 75（もとの明るさ）。境目の近く（±8）では変えない。`/status` の `light`（映像の明るさ）・`screen`（画面の明るさ）
  - 見守りをしない（`--watch-interval 0`）と映像が来ないので、画面の明るさは変えない
  - 画面の明るさは、スタックちゃんの中に覚えさせる（電源を入れ直しても同じ明るさから始まる）。変えるのは段が変わったときだけ

## AI-CAR のようすを答える

「ラズパイの温度は？」「車の前に何かある？」「Jetson のメモリは？」のように聞くと、ダッシュボード（ラズパイの `GET /api/status`、
`--car-url`、既定は `AI_CAR_URL` か `http://100.70.35.31:8080`）の今の値で答えます。読むだけで、走行・停止・再起動のボタンは使いません。

- 渡す値: 走行モード・自動運転の動き、LiDAR の前の距離、障害物、ラズパイの CPU・温度・メモリ・ディスク・起動からの時間、
  5V の電圧・電力・電圧低下の回数、AI HAT+ の温度、更新の数、ゲームパッド、カメラ、Jetson の CPU・GPU・温度・メモリ・電力（`car_status()` で短い文にする）
- ローカルのとき: 聞き取りに「ラズパイ」「ダッシュボード」「Jetson」「車」「LiDAR」「障害物」「CPU」「メモリ」「電圧」などが入っていたら、
  その文を Ollama の system に足す（3 秒でつながらなければ「ダッシュボードにつながりません」と伝える）。ネットは使わない
- ネットのとき: MCP の道具 `self.car.status` を XiaoZhi に見せ、XiaoZhi が呼んだら bridge が同じ文を返す

## ネットとローカルの切り替え

スタックちゃんはいつも Jetson につなぎ、ネットのときは bridge がネットの XiaoZhi へ中継します（ファームウェアの行き先は変えない）。

```
「ネットにして」（Jetson の whisper が聞き取る）→ 「ネットにつなぎます」→ bridge が XiaoZhi の OTA
  （https://api.tenclass.net/xiaozhi/ota/、スタックちゃんの Device-Id・Client-Id で）に聞いて wss につなぐ
  → スタックちゃんの hello を送り、声・JSON・MCP をそのまま中継（session_id だけ入れかえる）。顔は緑（0x00FF00）
「ローカルにして」（XiaoZhi の stt を bridge が見る）→ 中継をやめる → 顔は白 →「ローカルにもどりました」
```

- 言い方: 「ネット / インターネット / クラウド / NET」か「ローカル / LOCAL」のあとに
  「モード」「にして」「に切り替えて」「に変えて」「につないで」「に戻して」。「ネットで調べて」などでは切りかわらない
- 今の行き先は `mode.txt`、スタックちゃんの最後の OTA の問い合わせ（ネットの OTA にも同じものを送る）は `device_ota.json`（どちらも bridge と同じフォルダ）に残す。bridge やスタックちゃんを起動し直しても同じ。`/status` の `mode`（`local` / `net`）
- ネットにつながらない・登録が要るときは、「ネットにつながりませんでした。ローカルで話します。」と言ってローカルのまま
- ネットの間も、カメラの映像（`/camera/frame`）は Jetson に来ます。「写真を撮る」は、XiaoZhi が写真の送り先を自分のほうに変えるので使えません（ローカルにもどると、送り先を Jetson にもどす）
- XiaoZhi が会話を切っても、スタックちゃんとの会話は切りません。次に「スタックちゃん」と呼ばれたら、つなぎ直します
- ネットの間も Jetson を通るので、Jetson が止まると会話はできません（走行・安全停止には関係ありません）

### パソコンのときの「ネット」（調べるだけ）

パソコンを選んでいて、パソコンが動いているときの「ネットにして」は、XiaoZhi につながず、会話はパソコンの qwen2.5:14b（選んだ声の話し方・性格）のままにします。顔は緑、`mode.txt` は `net`、言うことは「ネットで調べながら話します。」。

- 毎回の質問で、ミニコンが調べた結果を会話の AI のプロンプトに足す（`web_info`、いっしょに調べて 6 秒まで、間に合わない所は飛ばす、全部で 1,500 字まで）
  - はじめに、パソコンの qwen2.5:14b に質問から検索ことばを作らせる（`search_words`、例「今ネットに繋がってるから、ウクライナの首相調べて」→「ウクライナ 首相」、約 0.2〜0.5 秒）。だめなら質問の文から「今の・誰・調べて」などを除くだけ
  - いつも: Wikipedia（日本語）の上から 2 記事の、はじめの説明と右の表（`incumbent`・`incumbentsince` など。今の首相・社長がわかる。API は 1 回だけ。何回も聞くと 429）
  - いつも: DuckDuckGo の上から 4 つのページの説明、Google ニュースの検索（`news.google.com/rss/search`、5 件の見出しと日付）
  - 「天気・雨・気温・傘」など: Open-Meteo（キー不要）の今・今日・明日・あさって。場所はネットの出口の IP（ip-api.com、1 回だけ）
  - 「ニュース・話題」など: Google ニュースのトップ 5 件
- ローカルのときは「ネットは見られないので、新しいことはわからないと言う」をプロンプトに足す
- パソコンが止まっているあいだの「ネット」は、今までどおり XiaoZhi の会話（声はミニコンの Kokoro）
- 2026/10 の実機（qwen2.5:14b）: 調べる 0.4〜1.0 秒、「今の日本の総理大臣は誰？」→「高市早苗殿ですわ」（四国めたん。調べないと「岸田文雄さん」と答えていた）

### 声ごとの話し方・性格

パソコンの VOICEVOX の声を選ぶと、ローカルの会話の AI の最初の決まり（`system_prompt`）を、その声のキャラクターにします（`PC_PERSONAS`・`PERSONA_PROMPT`）。「だれ？」「誰の声？」「名前は？」には、そのキャラクターの名前で答えます（このときはネットで調べない、`SELF_ASK`）。ミニコン（Kokoro）のときは今までどおり「スタックちゃん」です。

| 声 | 名乗る名前 | 話し方 |
|---|---|---|
| ずんだもん | ずんだもん | 一人称「ボク」、文の終わりはいつも「〜のだ」「〜なのだ」。明るく元気 |
| 四国めたん | 四国めたん | 一人称「わたくし」、「〜ですわ」「〜ですの」「〜かしら」。上品 |
| 春日部つむぎ | 春日部つむぎ | 一人称「あーし」、「〜じゃん」「マジで」。人なつっこい |
| 冥鳴ひまり | 冥鳴ひまり | 一人称「わたし」、おっとりした静かな丁寧語 |
| もち子さん | もち子 | 一人称「わたし」、やさしいお姉さんの丁寧語、ほめ上手 |

返事の中のキリル・アラビア・タイ・ハングルの文字は読まずに消す（`FOREIGN_TEXT`。qwen2.5 がときどき混ぜる）。漢字ばかりで、かなが漢字の 1/4 より少なく、「，你我们么」など中国語だけの字がある文も読まない（`is_chinese`）。

## 純正にもどす

書き換える前に、純正の全部（16 MB、版 1.5.1）を Jetson の `~/stackchan_backup/stackchan_factory_16MB.bin`
（SHA-256 `7dcebeb7bfb540c758df5d1936169511d5b9ab4116ed8ccd0cdb90a96e02fbad`）にとってあります。約 4 分です。

```bash
python3 esptool.py --chip esp32s3 -p /dev/ttyACM0 -b 921600 write_flash 0x0 ~/stackchan_backup/stackchan_factory_16MB.bin
```

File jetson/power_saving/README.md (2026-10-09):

# power_saving（Jetson の省電力を切る）

Jetson が置いたままで止まる（ping は返るが SSH・AI・状態の送信が止まる）ことの対策として、省電力を切る。今は Wi-Fi だけ。SSD の 2 つ（APST・HMB）は効かなかったので、2026-10-09 にもとに戻した（`install.sh` は前に入れた分を消す）。

| 設定 | ふつう | 今 | 効き始め |
|---|---|---|---|
| SSD（MAXIO MAP1202）の APST | 0.1 秒使わないと PS3（0.75 W、起きるのに 10 ms） | ふつうのまま（10/8〜10/9 は切 `nvme_core.default_ps_max_latency_us=0`） | 次の起動 |
| SSD に Jetson のメモリを貸す（HMB） | 16 MB 貸す（SSD は自分のメモリを持たない） | ふつうのまま（10/9 は切 `nvme.max_host_mem_size_mb=0`） | 次の起動 |
| Wi-Fi（RTL8822CE）の省電力 | `wifi.powersave = 3`（オン） | `2`（切） | すぐ（Wi-Fi が数秒切れる） |

- 2026-10 の調べ: SSD は電源を入れた 20 回のうち 9 回が unsafe shutdown、読み書きのエラーは 0。Wi-Fi は 3 日 17 時間で 16 回切れていた（電波 -45 dBm）。止まった原因かどうかは、まだわかっていない（止まったときの記録は `../health_log` で取る）。
- 2026-10-09: APST を切っても、SSD を差し直しても、SSD が起動から約 52・60 分で返事をしなくなった（`/sys/fs/pstore/console-ramoops-0` に `nvme nvme0: I/O ... timeout` → `reset controller` → `Device not ready; aborting reset, CSTS=0x1`）。次の手として HMB を切った。小さなファイルの読み書きは少し遅くなる（見込み）。
- 2026-10-09: HMB を切っても、起動から 43 分・17 分で同じように止まった（ふつうに終わらず切れた回数 10 → 14）。APST・HMB はどちらも効かなかったので、もとに戻した。止まるのは SSD そのものの見込みで、DRAM 付きの SSD に替えるのがよい（Samsung 980・WD SN770 も DRAM なしの HMB 型）。

## 入れ方

```bash
sudo ./install.sh
sudo reboot
```

確かめ方:

```bash
cat /sys/module/nvme_core/parameters/default_ps_max_latency_us   # 100000（ふつう）
sudo nvme get-feature /dev/nvme0 -f 0x0d                          # Current value:0x00000001（HMB はふつうのまま）
iw dev wlP1p1s0 get power_save                                    # Power save: off
```

もとに戻す: `/etc/NetworkManager/conf.d/zz-ai-car-wifi-powersave-off.conf` を消して再起動する。

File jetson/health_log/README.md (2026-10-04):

# Jetson の記録（止まったときの原因を調べるため）

放っておくだけで Jetson が止まる（ping は返るが SSH・Tailscale・状態の送信が止まる）ことが 2 回あった。
前の起動の記録がのこらない設定だったので、原因がわからなかった。そのための 2 つ。

- **journal をのこす**: `journald-persistent.conf` を `/etc/systemd/journald.conf.d/persistent.conf` に入れ、
  記録を `/var/log/journal` に書く（最大 1 GB）。再起動しても `journalctl -b -1` で前の起動の記録を読める
- **1 分ごとの様子**: `jetson-health.timer` が `jetson_health.sh` を 1 分ごとに動かし、1 行を journal に出す
  ```
  load 0.51/0.53 mem_avail 1360M free 104M swap 164M tj 47C fan 193/255 4431rpm down: none top: uvicorn:1418M ollama:469M python3:155M
  ```
  `down:` は止まっているサービス（ssh・tailscaled・jetson-status・ollama・whisper-server・jetson-face・jetson-oled）

## 入れ方（Jetson、JetPack 6.2 / L4T 36.4.3 で確認）
```bash
# このフォルダを ~/health_log にコピーする
sudo mkdir -p /etc/systemd/journald.conf.d /var/log/journal
sudo cp ~/health_log/journald-persistent.conf /etc/systemd/journald.conf.d/persistent.conf
sudo systemd-tmpfiles --create --prefix /var/log/journal
sudo systemctl restart systemd-journald
sudo journalctl --flush        # /run の記録を /var/log/journal へ移す（しないと次の起動まで /run のまま）
sudo cp ~/health_log/jetson-health.service ~/health_log/jetson-health.timer /etc/systemd/system/
sudo systemctl daemon-reload
sudo systemctl enable --now jetson-health.timer
```

## 止まったあとに見る
```bash
journalctl -b -1 -u jetson-health --no-pager | tail -20      # 止まる前の 1 分ごとの様子
journalctl -b -1 -k --no-pager | grep -i -E "oom|killed process|hung|blocked for|watchdog|panic"
journalctl -b -1 --no-pager | tail -50                       # 最後に何が起きたか
```

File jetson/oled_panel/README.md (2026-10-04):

# Jetson のケースの OLED と RGB の光

Yahboom の Jetson ケース（CUBE NANO）の横の小さな画面（OLED、SSD1306 128×32、白 1 色）に、Jetson の状態を出します。
Yahboom のイメージではなく JetPack をそのまま入れた Jetson では、この画面は何も出ないので、そのかわりです。

大きな文字（DejaVu Sans Bold 14 px）の 2 行で、3 秒ごとに画面を切り替えます（値は 1 秒ごとに新しくします）。
```
CPU   12% 45°C      CPU・GPU の負荷率と温度
GPU    3% 44°C
---
RAM    3.1/7.4G     メモリ（使用 / 全部、GiB）と / のディスク（GB）
SSD    120/866G
---
Wi-Fi               IP アドレス（Tailscale・Wi-Fi・LAN を 1 つずつ）
     192.168.11.23
```

ケースの RGB の光（I2C 0x0E、Yahboom の「I2C Communication Protocol」の 0x04 特効・0x05 速さ・0x06 色）は、
AI の負荷（GPU の負荷率の 5 秒平均）で、呼吸（特効 1）の色と速さを変えます。変わったときだけ書き、`journalctl -u jetson-oled` に出します。

| GPU の負荷率 | 色 | 速さ |
| --- | --- | --- |
| 10 % より下 | 青 | 低速 |
| 10〜40 % | 緑 | 中速 |
| 40〜70 % | 黄 | 中速 |
| 70 % 以上 | 赤 | 高速 |

- CPU が 70 °C 以上（`OLED_HOT_C` で変えられる）のときは、負荷にかかわらず赤の高速
- ファン（0x08）は変えません

- I2C の 7 番（40 ピンの 3・5 番）。`i2cdetect -y -r 7` で `3c`（OLED）と `0e`（ケースの基板）が見えれば、つながっています
- 標準ライブラリと Pillow だけで動きます（JetPack の `/usr/bin/python3`）。CPU は約 2 %、メモリ約 16 MB
- サービスを止めると画面を消します（RGB の光はそのまま）

## 入れ方（Jetson、JetPack 6.2 / L4T 36.4.3 で確認）
```bash
# このフォルダを ~/oled_panel にコピーする（ユーザー jetson は i2c グループに入っている）
sudo cp ~/oled_panel/jetson-oled.service /etc/systemd/system/
sudo systemctl daemon-reload
sudo systemctl enable --now jetson-oled.service
journalctl -u jetson-oled -f
```

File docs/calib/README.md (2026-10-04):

# 2 眼カメラのキャリブレーション

2 眼カメラで距離を測る前に、左右のレンズのゆがみ・向きのずれ・レンズの間隔を測る。

## 用意するもの

- `checkerboard_9x6_24mm_A4.pdf` を A4 横に **100 %（実際のサイズ）** で印刷する。下の線が 100 mm になっているか、定規で確かめる
- 1 マスの大きさを定規で測っておく（24 mm からずれていたら、計算のときに `--square-mm` で直す）
- 印刷した紙は、曲がらないように板や段ボールに平らに貼る

## 撮影（ダッシュボード）

1. 車を止めて、模様をカメラに向けて持つ。左右どちらの目にも模様の全部が入るようにする
2. カメラカードの「キャリブレーション」の「撮影」を押す（API トークンが必要）
   - 左右とも見つかると「保存 N 組目」。見つからないと、見つからなかった側（左・右）が出る
3. 場所と向きを変えて、20 組くらい撮る
   - 画面の真ん中・四すみ・はしにも写す（はしのゆがみを測るため）
   - 近く（約 30 cm）と遠く（約 1.5 m）を混ぜる
   - 左右・上下に 30° くらい傾けたものも混ぜる
   - ぶれないように、押すときは止めて持つ

画像は Pi の `~/AI-CAR_ws/calib/stereo/pair_NNN_left.png` / `pair_NNN_right.png` に保存される（片目 1280×720）。

## 計算（Pi）

```bash
source /opt/ros/jazzy/setup.bash
source ~/AI-CAR_ws/install/setup.bash
ros2 run ai_car_web stereo_calibrate --square-mm 24
```

`~/AI-CAR_ws/calib/stereo/stereo_calib.yaml` に、左右のカメラの値（`K1` `D1` `K2` `D2`）、左右の向きと位置（`R` `T`）、平行化の値（`R1` `R2` `P1` `P2` `Q`）を書く。

よしあしの目安:

- 誤差（`rms_stereo_px`）: 0.5 px 以下ならよい。1 px を超えたら撮り直す
- 平行化後の上下のずれ（`rectified_y_error_px`）: 0.5 px 以下
- レンズの間隔（`baseline_m`）: 約 0.060 m
- 広角でゆがみが大きく誤差が下がらないときは `--rational` を付ける

## 距離の計算（stereo_depth_node）

- `stereo_calib.yaml` ができると、`stereo_depth_node` が自動で読む（ファイルが変わると読み直す。再起動はいらない）
- ダッシュボードのカメラカードの「2眼の距離」に、通り道の中のいちばん近い物の距離が出る。「距離の画像」を押すと、映像が距離の色（近い = 赤、遠い = 青、測れない = 黒）に変わる
- 「2眼の距離」の行にマウスを乗せると、床の高さ（中央値）が出る。0 m から 2 cm 以上ずれるときは、`dashboard.yaml` の `stereo_depth_node` の `camera_height_m`・`camera_pitch_deg` を合わせる
- 白い壁・ガラス・真っ暗な所は、左右で同じ所が見つからず測れない（黒くなる）

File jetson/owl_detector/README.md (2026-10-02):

# Jetson の物体検出（NanoOWL）

AI-CAR のカメラ画像を Jetson Orin Nano Super で NanoOWL（言葉で物を探す AI）にかけ、
「段ボール箱」「袋」のような名前と画面の位置を AI-CAR へ送ります。AI-CAR の YOLOv8m（80 種類）に
ない物も、`prompts.json` に英語の言葉を足せば探せます。

```
AI-CAR  GET /api/camera/snapshot ──→ Jetson（NanoOWL、約 35 ms / 枚）
AI-CAR  POST /api/jetson/detections ←── 名前・信頼度・位置（重なった枠は 1 つにまとめる）
        → /jetson_detections → perception_node が LiDAR の距離を付ける → ダッシュボードに水色の枠
```

表示だけで、AI-CAR の速度（停止・減速）には使いません。

## ファイル
- `owl_detector.py`: 本体。`dustynv/nanoowl:r36.3.0` コンテナの中で動かす
- `prompts.json`: 探す言葉（`prompt`、英語）と表示する名前（`label`）。`label` が空の言葉（窓・カーテン）は、
  まぎらわしい枠を吸わせるためだけに使い、送らない
- `jetson-owl.service`: Jetson の systemd サービス

## 入れ方（Jetson、JetPack 6.2 / L4T 36.4.3 で確認）
```bash
sudo docker pull dustynv/nanoowl:r36.3.0
mkdir -p ~/owl/hf
# このフォルダを ~/owl_detector にコピーする
sudo install -m 600 /dev/null /etc/jetson-owl.env
sudoedit /etc/jetson-owl.env   # 次の 2 行を書く
#   AI_CAR_URL=http://100.70.35.31:8080
#   AI_CAR_API_TOKEN=<AI-CAR の dashboard_node の API トークン>
sudo cp ~/owl_detector/jetson-owl.service /etc/systemd/system/
sudo systemctl daemon-reload
sudo systemctl enable --now jetson-owl.service
journalctl -u jetson-owl -f
```

1 枚だけ試すとき（結果を表示するだけで、AI-CAR には送らない）:
```bash
sudo docker run --rm --runtime nvidia --network host \
  -v ~/owl_detector:/owl_detector:ro -v ~/owl/hf:/root/.cache/huggingface \
  dustynv/nanoowl:r36.3.0 python3 /owl_detector/owl_detector.py --once
```

## 分かっていること（2026/10 実機）
- 960 × 540 の画像 1 枚で約 35 ms（言葉 4〜5 個）
- 袋 0.69、段ボール箱 0.62 で見つかった。白い箱も見つかるが「段ボール箱」（0.50）になる。
  「a white box」「a box」では段ボール箱より低い点しか出ず、箱の色の言い分けは苦手
- 何もしないと 1 つの物に枠が何個も重なるので、重なり（IoU）0.5 以上の枠と、80 % 以上がほかの枠の中に入る枠は捨て、点の高い 1 つだけ残す

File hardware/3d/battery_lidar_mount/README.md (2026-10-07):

# バッテリー 2 個 + RPLIDAR A1M8 + ラズパイ + 前カメラ マウント

天板（154 x 200 mm）に載せる部品。
- 前側: CIO SMARTCOBY Pro SLIM を 2 個重ねて収める箱（後ろの壁に DROK 降圧コンバーターの受け）と、その上に RPLIDAR A1M8・前カメラ（Raspberry Pi Camera Module 3 Wide SC0874。前の USB 2 眼カメラ用は `front_cam="stereo"`）・IMU（GY-BNO055）を載せるふた
- 後ろ側: Raspberry Pi 5 台（AI HAT+ / Motor HAT はこれまでどおり Pi の上に重ねる）。Pi のまわりにはほかの部品を置かない（液晶は外した。IMU は LiDAR の下へ移した）。Pi は左に寄せ、電源ボタンはカバーの左の穴から押せる。右の USB / LAN 側はカバーの壁まで約 61 mm あき、ストレートの USB プラグも入る

| ファイル | 内容 |
|---|---|
| `battery_lidar_mount.scad` | OpenSCAD ソース（寸法はすべて先頭のパラメーター） |
| `box.stl` | バッテリー箱 + DROK の受け（フランジを下にして印刷、サポート不要） |
| `lid.stl` | ふた + LiDAR 台（板を下にして印刷、サポート不要） |
| `pi_base.stl` | ラズパイ台（板を下にして印刷、サポート不要） |
| `cam_mount.stl` | Camera Module 3 Wide の板（裏を下にした向きで出力済み、サポート不要） |
| `cam_mount_stereo.stl` / `cover_stereo.stl` | 前の USB 2 眼カメラ用の板とカバー（`-D 'front_cam="stereo"'`） |
| `bumper.stl` | 前後バンパー（前後共通、2 個印刷。上面を下にした向きで出力済み、サポート不要） |
| `assembly.png` / `top.png` / `side.png` / `motor_recess.png` / `sensors.png` / `bumper_under.png` / `bumper_spring.png` / `bumper_hook.png` / `tof_view.png` / `screw_holes.png` / `cam_post_nut.png` | 組み立てイメージ / 真上 / 横 / モーターのネジのくぼみ（下から見た図、左右が反転。赤がネジの範囲） / IMU の台（LiDAR の下） / バンパーを下から / バンパーのばね / バンパーの爪（断面） / 落下防止センサーの視野（横から） / ネジ穴の断面 / ふたの前端の左の柱（M3 の貫通穴と M2 のナットのくぼみ） |
| `wiring.png` / `wiring_front.png` / `wiring_top.png` | 配線経路の目安（後ろ斜め / 前斜め / 真上。`-D show_cables=true` で描画） |
| `camera_mount.png` | Camera Module 3 Wide の取付（前から。白が板） |
| `cam_mount_back.png` / `cam_nut_relief.png` | カメラの板の裏（M2 ナットの六角のくぼみ） / ふた・箱の前の面の逃げ穴（M2 x 10 とナットを入れた状態） |
| `wiring_camera.png` | Camera Module 3 Wide のフラットケーブルの経路（白。`-D show_cables=true`） |
| `drok_holder.png` | DROK の受け（箱の後ろの壁、Pi 側から見た図） |
| `cover.stl` | 上面カバー（Camera Module 3 Wide 用。上面を下にした向きで出力済み、サポート不要） |
| `cover_assembly.png` / `cover_right.png` / `cover_rear.png` / `cover_hook.png` / `battery_display.png` | カバーを付けた状態 / 右側面の充電口 / 後ろ斜め（通気口） / フックの断面 / バッテリーの残量表示の窓（`-D show_cover=true` で組立図に描画） |

## ネジ穴

| 場所 | ネジ | 穴の形 |
|---|---|---|
| 天板への取付（箱のフランジ、ラズパイ台の腕、バンパーの腕） | 天板の今のネジ（長いものに交換） | Ø4.4 の通し穴 |
| ふた → 箱のボス（4 か所） | M3 x 12 mm | ふた: Ø3.4 の通し穴 / 箱: M3 のねじ込み穴 深さ 12 mm |
| LiDAR → ふたの柱（4 か所） | M2.5 x 8 mm | 下から座ぐり Ø5.2、上端 4 mm に Ø2.9 の通し穴 |
| Camera Module 3 Wide → 板の支柱（4 か所） | M2 x 6 mm（ナットで留めるときは M2 x 8〜10 mm） | 支柱 Ø4.6・高さ 4 mm に Ø2.5 の下穴（板を貫通）。板の裏に M2 ナットの六角のくぼみ（二面幅 4.4 mm、深さ 1.8 mm、`wcam_nut_af`・`wcam_nut_d`）。ふた（上の 2 本）と箱（下の 2 本）の前の面に、ナットとネジの先の逃げ穴（Ø6.5、深さ 4 mm、`wcam_relief_d`・`wcam_relief_l`） |
| カメラの板の耳 → ふたの前端の柱（左右 2 か所） | M3 x 8 mm | 耳: Ø3.4 の通し穴 / 柱: M3 のねじ込み穴（Ø2.5、柱を貫通） |
| Pi 5 の M2.5 六角支柱（幅 5 mm）→ ラズパイ台のボス（4 か所） | M2.5 x 6 mm（台の裏から支柱のメスねじへ） | 支柱を差し込む丸い穴 Ø6.2 深さ 5 mm、底に Ø2.9 の通し穴、裏から座ぐり Ø5.2 深さ 2 mm |
| DROK 降圧コンバーター → 箱の後ろの壁 | ネジなし（結束バンド 1 本） | 基板に取付穴がないため、受けの溝に立てて結束バンドで締める |
| 上面カバー → 天板 | ネジなし（左右 4 個のフック） | 天板の左右の端の裏に爪（奥行き 2.3 mm）が掛かる |

- ねじ込み穴は `screw_mode` で形を切り替える。どちらも入口に面取りを付ける
  - `"tap"`（既定）: 下穴（M2 Ø1.7 / M2.5 Ø2.1 / M3 Ø2.5）。普通の小ネジをねじ込むと、ネジ自身が樹脂にねじ山を切る。M2〜M3 のねじ山は細かすぎて FDM ではきれいに出ないので、ねじ山は形にしていない
  - `"insert"`: 熱圧入インサート（真鍮）用の穴（M2 Ø3.2 / M2.5 Ø3.6 / M3 Ø4.0）。何度も外すところや、強く締めたいところに向く。穴径はインサートの製品に合わせて `insert_d` を直す
- 下穴がきつい、またはゆるい場合は `tap_d` を 0.1 mm ずつ変える

## 主な寸法

- 箱の外形: 103.8 x 75.2 x 38.4 mm（内寸 96.8 x 67.6 x 33.4 mm）。バッテリーの実測 98.2 x 66.8 mm に対し、前後のすき間は片側 0.4 mm。前後の壁は 3.8 mm（外形はそのままで内側へ厚くした）。左右の壁は、開口側が 2.5 mm、反対側が 4.5 mm（`end_fill`。実物では長手方向に約 2 mm のすき間があったので、2 mm のプレートで確かめてから内側へ 2 mm 厚くした）。床は 5 mm（フランジ 3 mm より 2 mm 厚い。下のモーターのネジのくぼみの分）。開口側の角にあるふたのボス 2 本（Ø8）がバッテリーの通り道に前後 5.8 mm ずつかかるので、バッテリーはふたを外して上から出し入れする。開口側の後ろのボス（X 131.4 / Y 118.4 mm、`boss_open`）は、バッテリーに差す L 字の USB プラグが当たるので、下（フランジの上から 5 mm）と上（箱の上端から 5 mm、`boss_keep`）だけ残して真ん中を抜いた。抜いた所の高さは、天板から 8〜33.4 mm（25.4 mm）。上の部分は上端から 5 mm の厚さだけで作り、それより下には何も作らない。上から見て三角の板にして、後ろの壁の端と、壁の外側に沿わせた長さ 20 mm・厚さ 2 mm の板（`boss_tie_l`・`boss_tie_t`）につなぎ、壁と接する面を約 120 mm²（20 × 5 mm と、壁の端 3.8 × 5 mm）にした。柱の部分は壁の端から約 6.5 mm 空中に出るので、スライサーでそこにだけサポートを付けて印刷する
- フランジ: 148 x 92 x 3 mm。天板の前側 4 穴（四隅 2 個 + 前端から 90 mm の 2 個）に合わせた Ø4.4 穴
- LiDAR 取付柱: 高さ 48 mm、太さ Ø8.5。LiDAR 底面の M2.5 ねじ穴に、ふたの裏から柱の中を通したネジで留める（柱の下から Ø5.2 の座ぐりでネジ頭を沈め、上端 4 mm だけ Ø2.9 の通し穴を残す）。座ぐりは柱の下から 48 mm あるので、軸が Ø5 より細く、長さ 50 mm 以上のドライバーを使う。穴位置はデータシート Figure 5-2（ヘッド側 56 mm 間隔、モーター側 40 mm 間隔）
- LiDAR 取付面の高さ: 天板上面から 90.4 mm（カバーの上面 82.4 mm より 8 mm 上）。モーター側の先端は天板前端から約 5 mm はみ出す
- LiDAR の位置: 箱の中心から左へ 8 mm（`lidar_dx`）。ROS の TF（base_link → laser）の横オフセットにも反映する
- Camera Module 3 Wide（SC0874、`front_cam = "wide"`、既定）: 寸法は公式の図面 RP-008155-DS-1 から（実物は未確認）。基板 25 x 23.862 x 1.12 mm、M2 の穴は左右 21 mm 間隔・基板の下の端から 2.0 / 14.5 mm、レンズの中心は下の端から 14.4 mm、レンズは基板の表から 8.3 mm・太さ Ø6.95 mm、画角 横 102°・縦 67°
  - 位置: レンズの中心を前の 2 眼カメラと同じ X 69 mm（LiDAR の回転中心）・天板から 40.4 mm にそろえた。基板は天板から 26.0〜49.9 mm、X 56.5〜81.5 mm
  - 向き: フラットケーブルの端子を上にして付ける（ケーブルをすぐ後ろのふたの上へ出すため）。映像は上下さかさまになるので、ソフトで 180° 回す
  - 前後: 板（厚さ 2.5 mm）の裏をふたの前端の面（Y 189.6 mm）に当てる。板から高さ 4 mm の支柱（Ø4.6。裏の端子 約 3 mm の逃げ）の先に基板の裏（Y 196.1 mm）。レンズの先は Y 205.5 mm で、カバーの前の壁の内側より 1.0 mm 奥（カバーの中にかくれる）
  - 板: 87 x 33.9 mm（左右の耳とふたの柱への M3 は 2 眼用と同じ位置・同じネジ）。板の上の端は天板から 45.9 mm で、端子から出たケーブルは板の上を越えて後ろへ
  - ナットの逃げ: 板の裏は、上の 2 本（天板から 40.5 mm）がふた（38.4 mm から上）、下の 2 本（28 mm）が箱の前の面に当たる。M2 x 6 mm のネジの先は板の裏から出ないが、ナットで留めると出るので、板の裏に M2 ナットが入る六角のくぼみ（二面幅 4.4 mm、深さ 1.8 mm。厚さ 1.6 mm のナットが裏から出ない）を開け、ふたと箱の前の面にナットの角とネジの先の逃げ穴（Ø6.5、深さ 4 mm）を開けた。M2 x 10 mm でもネジの先は逃げ穴の底の 1.6 mm 手前。箱の前の壁は逃げ穴の後ろに 1.8 mm 残る。ナットとネジがふた・箱と重ならないことを OpenSCAD で確かめた
  - 届いたら実測して直すところ: レンズの長さ（`wcam_lens_l`）、裏の端子の厚さ（`wcam_conn`）、穴の位置（`wcam_hole_z`）
- 2 眼カメラ（3D USB Camera、`front_cam = "stereo"`）: 基板 80 x 17 mm（実測）、厚さ 1.6 mm（仮）、左右のレンズの間隔 約 60 mm、レンズは基板の表から 26 mm・いちばん太い所 18 mm、裏の部品は 2 mm（実測）。USB 端子を上にして、ふたの前（LiDAR のモーターの下）にレンズを前に向けて立てる。左右のレンズの真ん中を LiDAR の回転中心にそろえた（X 69 mm、`scam_cx`）
  - 高さ: 基板の上端は LiDAR のモーターの下端（天板から 63.9 mm）より 15 mm 下（`scam_usb_room`、L 字の USB-C プラグを上から差して後ろへ曲げる分）。基板は天板から 31.9〜48.9 mm で、ふたの上面（42.4 mm）より下の箱の前にかかる。レンズの中心は天板から 40.4 mm（`scam_lens_z` 0 の仮の値）
  - 前後: 板（`cam_mount.stl`、厚さ 2.5 mm）の裏をふたの前端の面（Y 189.6 mm）に当てる。板から高さ 2.5 mm の支柱（Ø4.6、裏の部品 2 mm + 0.5 mm）の先に基板の裏（Y 194.6 mm）が当たり、レンズの先は Y 222.2 mm（LiDAR の中心から前へ 79.2 mm、カバーの前の壁の外側より 13.3 mm 前）
  - 固定: 基板の四隅の穴（中心はふちから 1.5 mm、X 30.5 / 107.5 mm・高さ 33.4 / 47.4 mm）に前から M2 x 6 mm を 4 本（支柱と板に Ø2.5 の下穴、`scam_hole_d`。Ø1.7 では印刷で約 0.5 mm につぶれた）。上の 2 本の後ろはふたの柱に当たるので、柱の前の面に M2 ナットが入る六角のくぼみ（二面幅 4.4 mm、深さ 2.5 mm、`scam_nut_af`・`scam_nut_d`）と、ネジの先が通る Ø2.4 の穴（柱を貫通）を開けた。ナットで留めるときは M2 x 8〜10 mm を使い、ナットをくぼみに入れてから板を当てる。板の左右の耳（X 25.5〜33.5 mm と 104.5〜112.5 mm、高さ 57.9 mm まで）を、ふたの前端の柱 2 本（奥行き 6 mm）に前から M3 x 8 mm で 1 本ずつ留める（柱の M3 の穴は後ろまで貫通）。M2 のネジの頭（Ø4.4）がレンズの台にかかるときは、頭の小さいネジにする
  - 板の左右の端は、カバーの前のリブ（X 21〜25 / 129〜133 mm）から 0.5 mm 以上離れる。耳の上の M3 は、ふたの左前の M3 のネジの頭とも重ならない
  - 今は 180° 回して使っている（`dashboard.yaml` の `stereo_camera_node` の `rotate_180: true`、左目）。この板に USB 端子を上にして付けたら、`rotate_180` を false にする
  - USB ケーブル: L 字のプラグを上から差して後ろへ曲げ、板の上（中央は高さ 45.9 mm まで）を越えて、LiDAR の前の柱 2 本の間からふたの上の結束バンド用ブリッジ 2 か所（X 77 / Y 166 と、ふたの後ろ端の X 86 / Y 119.4）で留めて Pi の USB へ
- ラズパイ 3 段（Pi 5 + AI HAT+ + Motor HAT、実測 45 mm）: 台のボスで最大 9 mm 高くなっても上端は約 54 mm。LiDAR 取付面（90.4 mm）より低く、LiDAR ヘッドとは前後に約 30 mm 離れる
- IMU（GY-BNO055）: 基板 12 x 20 mm（`imu_board`）。ふたの上、LiDAR のヘッドの下の後ろ寄り（後ろの柱 2 本の間、`imu_c` = [65, 122.3]）に置き、台を Z まわりに -90° 回して（`imu_rot`）長辺を左右に向けた。台の外形は X 53.1〜76.9 mm・Y 118.9〜130.2 mm で、後ろの柱（X 45.3 まで / X 92.8 から）、残量表示の窓、LiDAR、カバーとは重ならない。台の上端は天板から 72.3 mm で、LiDAR の中央の基板の下（82.4 mm）まで約 10 mm あく。ピンヘッダーは下向きで、後ろ（Pi 側）の長辺に並ぶので、その長辺には壁を付けずに開けてある。残りの 3 辺は厚さ 1.6 mm の壁の内側の段で縁 1 mm を下から受け（`imu_ledge`）、前の長辺の壁の上端の出っ張り（内側へ 3 mm、厚さ 3 mm。`imu_lip`・`imu_lip_t`）で上から押さえる。基板はジャンパー線を差したまま、後ろの開いた側から斜めに入れて、前の縁を出っ張りの下に差し込んでから段に載せる。基板の下はふたの上面から 25 mm（`imu_lift`）空いていて、コネクターが収まる。後ろの縁が浮く場合は両面テープかホットボンドで 1 点留める。取り付けの向きが変わったので、ROS の IMU の軸の向きの補正はまだしていない
- モーター取付ネジのくぼみ: 天板の上にモーター取付ネジの頭が 3 mm 出ている範囲（28 x 28 mm が 4 か所。左右の端から 7 mm、前後の端から 38 mm、`motor_scr_pts`）の上に載る部品の底に、深さ 3.5 mm・29 x 29 mm のくぼみ（ネジとのすき間は横と上に 0.5 mm、`recess_clr`）を付けた。くぼみの上には 1.5 mm 残す（`recess_roof`）ので、くぼみのある部分は厚さ 5 mm（`recess_t`）
  - 前の 2 か所（Y 134〜162 mm）: 箱。バッテリーの床を 5 mm にし、フランジだけの左右の部分にも厚さ 5 mm の台（くぼみの周り 1.5 mm）を足した。これで箱・ふた・LiDAR・カメラ・IMU が 2 mm 高くなった。左の結束バンドの受け 2 個は、くぼみの前後（Y 128 / 168 mm）へずらした
  - 後ろ左・後ろ右: ラズパイ台の腕と Pi の受けはネジの範囲にかからない（液晶の台をなくしたので、後ろ左もくぼみはいらない）
  - 高さが 3 mm より高いネジ、または範囲からはみ出すネジがあれば、`motor_scr_h` / `motor_scr_pts` を直して STL を作り直す
- バンパー: 天板の端から 33 mm 前（後ろ）に出す（`bump_out`）。固定側（腕 + 板 + センサー受け）と前面の板を分け、横長の板ばね 4 枚（有効長 30 mm、板厚 0.8 mm）でつなぐ。板ばねは片端を固定側、反対の端を前面の板につなぎ、向きを交互にして前面の板が平行に動くようにしてある。ぶつかると前面の板だけが後ろへ 4 mm 逃げ（`bump_travel`）、ストッパー 3 本（長さ 6.8 mm）に当たって止まる。止まったときも、板ばねと固定側・前面の板のあいだには 1 mm のすき間が残る（`spring_clr`）。前面の板は天板上面から 15 mm 下まで伸ばす（`bump_drop`）。手で触る縁（上の板の上下の縁と角、前面の板の上下左右の縁）は 1 mm の面取り（`bump_edge`）。左右の腕の下に爪（X 7.2〜18 mm と 136〜146.8 mm、高さ 3 mm、`bump_hook_x`）があり、前は箱のフランジの前の縁（Y 196 mm）、後ろはラズパイ台の腕の端（Y 4 mm、平らにしてある）に 0.1 mm のすき間（`bump_hook_clr`）で当たる。ぶつかったときの力は、ネジではなくこの左右 2 か所の面（11 × 3 mm）で受ける
  - 4 mm 逃げたときの曲げひずみは約 1.1%（`spring_strain`、3 t δ / L² による）。PLA の降伏ひずみ（約 2%）の半分ほどなので、PLA で印刷できる（PETG でもよい）。板ばねは印刷の層に沿って曲がる向き。全体の反力は計算上 約 8 N（PLA）。硬さは `spring_t` と `spring_x`（板ばねの長さ）で変えるが、変えたら `spring_strain` が PLA で 1.2% を超えないことを確かめる
  - 一体で印刷でき、組み立ては不要
  - 固定: 前は箱のフランジ、後ろはラズパイ台の腕の上に重ね、四隅の穴で共締め（ネジはさらに 4 mm 長く）。腕は箱のボスを避けて左右 15 mm 幅
  - センサーは固定側に付いているので、ぶつかっても向きは変わらない
- 落下防止センサー（VL53L1X、Dovhmoh 25 x 10.7 x 3.2 mm）: バンパー中央の下に付けた斜めの受けに、上から落とし込む。真下から進行方向へ 45° 傾けて前方の床を見る（`tof_tilt`）。受けの中心は天板の端から 14 mm 前、天板上面から 5 mm 下（`tof_dy`、`tof_drop`）。45° にしても上から落とし込む穴が天板の角・箱のフランジにかからない位置まで前へ出してある。基板の下面のレンズのカバー（実測 12.2 x 7.4 mm、`tof_cover`。中心は基板の中心から約 1.9 mm ピンと反対側へ寄り、縁は基板の長辺まで来る）が入るよう、窓は幅 13.4 mm（`tof_win`）で、長辺の方向は受けの穴いっぱいに開けた。基板は左右の耳（丸穴の部分、各 5.8 mm）で受け、丸穴の部分は開けていない。窓の上下は対称なので、ピンの列がどちら側でも入る。ピンは上向きで、配線は同じ穴から上へ出す。視野は前面の板の下を通る
  - 床を見る位置は、センサーから前へ「床までの高さ x tan 45°」＝床までの高さと同じ距離（バンパーの前面はセンサーの 19 mm 前）。測る距離は高さの約 1.41 倍（最短 4 cm）
  - 視野 27° の上の端は、前面の板の下端より約 3 mm 下を通る（`tof_view.png`）。55° を超えると上の端が前面の板に近づき、60° で当たる
  - 30° から 45° に変えた理由: 30° では床を見る位置がバンパーの前面から 1〜3 cm 先しかなく、0.3 m/s（手動の最高速度）では止まるのが間に合わない。45° なら、床から天板の下面まで 70 mm（実測）で、床を見る位置はバンパーの前面から約 5 cm、前輪の接地点から約 14 cm 先（前輪の車軸は天板の前端から約 52 mm 後ろ。OSOYOO のシャーシの図面）
  - VL53L1X の I2C アドレスは初期値 0x29 で、2 個とも同じ。GY-BNO055（0x29 で使用中）とも重なるため、XSHUT をそれぞれ GPIO につないで起動時にアドレスを変えるか、BNO055 を 0x28 に戻す必要がある
- DROK 降圧コンバーター（B09JKHD3SH、12V → 5.2V / 5A、USB-A 出力）: 基板 63 x 27 mm（商品画像の寸法）、基板の裏から部品の頂点まで 13 mm と仮定（`drok_board`、`drok_h`）。取付穴がないので、箱の後ろの壁（Pi 側）に長辺を横にして立てる。X 41.5〜104.5 mm、高さは天板から 5.5〜32.5 mm でふたより下
  - 下端はフランジの上の棚に載せ、前側 2 か所の縁（高さ 1.5 mm）で押さえる。裏は壁から 3 mm 浮かせ（リブ 3 本、`drok_gap`）、裏に出たピンと通気スロットを逃がす
  - 固定: 中央のリブの中に縦の穴（結束バンド用、幅 4.5 mm）がある。結束バンドを上から差し込み、基板の下（フランジとの間 2.5 mm）をくぐらせて前に出し、部品面を縦に回して締める。コイル（中央の四角い部品）の上を通すと、ほかの部品に当たりにくい
  - 入力（DC ジャック・入力端子）を左、USB-A 出力を右に向ける。部品面は Pi 側を向き、Pi 3 段の前端まで約 18 mm 空く
- ラズパイ台: Pi 5 の穴（58 x 49 mm）に高さ 6 mm のボス（Ø9.4）。Pi に付けた M2.5 の六角支柱（幅 5 mm）を、ボスの丸い穴（Ø6.2、六角の角と角の間 5.77 mm より大きいので、支柱を回さずに差し込める）に 5 mm 差し込み、台の裏から M2.5 x 6 mm のネジで留める（ネジ頭は裏の座ぐり Ø5.2 深さ 2 mm に沈む）。Pi の基板の下面の高さは `pi_z` = 台の上面 + 6 − 5 + 支柱の長さ `pi_so_l`。カバーの上面の裏（80 mm）に当たらない支柱の長さは 31 mm まで。天板の後ろ側 4 穴（四隅 2 個 + 後端から 90 mm の 2 個）に 4 本の腕で留める。USB / LAN は右（+X）、GPIO は前向き。基板の中心は X 47 mm（`pi_cx`）で、基板の左の短辺（電源ボタン・microSD 側）は X 4.5 mm（カバーの左の壁の内側から 4.8 mm）、右の短辺は X 89.5 mm。USB / LAN の口（基板から約 4 mm 出る）からカバーの右の壁の内側（X 154.3 mm）まで約 61 mm あくので、ストレートの USB プラグ（長さ約 40 mm を見込んだ箱）でもカバーに当たらない（OpenSCAD で確認）。台は Pi の受け 4 か所・腕 4 本・モーター線の開口だけで、Pi のまわりにほかの部品はない

## 配線

経路は `wiring*.png`（`-D show_cables=true`）。寸法はデータシート（RPLIDAR A1 Figure 5-2、Raspberry Pi 5 機械図面）からの読み取りで、実物では確かめていない。

| 配線 | 経路 | 確保してある寸法 |
|---|---|---|
| Camera Module 3 Wide（フラットケーブル 22 ピン → 15 ピン、幅 16 mm） | 基板の裏の上の端子 → 上へ出して板の上を越え、ふたの上を後ろへ（LiDAR の前の柱 2 本の間）→ Y 170〜184 mm で 2 回折って右へ 16 mm → 結束バンド用ブリッジ 2 か所（X 77・Y 166、X 86・Y 119.4）の上 → IMU の台と後ろ右の柱の間 → ふたの後ろ端から DROK の上へ下りる → Pi 3 段の前から Pi と AI HAT+ の間を通して Pi の CAM の口へ | 経路は約 21 cm。**30 cm** のケーブルを使う（15 cm 以下は届かない）。IMU の台と柱のすき間は 15.85 mm で、幅 16 mm のケーブルはふちが軽く当たる（少しななめにして通す） |
| 2 眼カメラ（USB） | 基板の裏の USB 端子 → ふたの上を後ろへ（右前の結束バンド用ブリッジ X 77・Y 166 mm）→ 後ろ端のブリッジ（X 86 mm、IMU の台と後ろ右の柱の間）で LiDAR の線と一緒に留める → Pi 右側の USB-A | 必要な長さは約 25 cm。ふたの上はカメラの裏から LiDAR のモーターの下を通る（モーターの下端 63.9 mm、ふたの上面 42.4 mm）。L 字の USB プラグを推奨 |
| LiDAR（ハーネス + USB 変換基板 → Pi の USB） | 変換基板はふたの上、ヘッドの下（基板部の下に約 15 mm の空き）の左寄り（X 72 mm より左、IMU の台の前の Y 130 mm より前。右はカメラの USB ケーブル）に両面テープで貼る。ハーネスと USB ケーブルは IMU の台の前を右へ回し、ふたの後ろ端の結束バンド用ブリッジ（X 86 mm）で留め、Pi 右側の USB-A へ | USB-A の差し込み側は天板の右端まで約 30 mm。L 字の USB プラグを推奨 |
| バッテリー → 12 V → DROK の入力 | 箱の右の開口 → 箱の後ろを DROK の前の低いところに沿って左へ → DROK 左端の DC ジャック（5.5 x 2.1 mm）か入力端子 | 約 15 cm。DROK 左端から天板の左端まで約 40 mm |
| DROK の USB-A → Pi 5 の USB-C | DROK 右端の USB-A → フランジ右後ろのブリッジ → 天板の右端に沿って後ろへ → 後ろ端に沿って左へ → Pi 後ろ側の USB-C | USB-A 側は右の開口より後ろ（Y 110 mm 以下）を通るので、バッテリーの出し入れをじゃましない。後ろのバンパーの上面（天板から 7 mm）より上をプラグが通る。30 cm 程度の USB-A → USB-C（C 側は L 字を推奨） |
| バッテリー → 12 V → Motor HAT | 同じく右側から後ろへ回し、Motor HAT 後ろ端の端子台へ | Pi の後ろ（Y 0〜22 mm）は空けてある |
| モーター線（4 本） | 天板の開口 → ラズパイ台の中央開口（後ろの縁まで開けてある）→ Pi の後ろ → Motor HAT の端子台 | 開口 48 x 50 mm（後ろ側は台の縁まで） |
| IMU（I2C 4 本） | ピン下向き → 台の後ろの開いた側から出す → ふたの後ろ端から Pi の前の GPIO ヘッダー（1・3・5・9 番）へ | 約 10 cm（20 cm のジャンパー線）。ピンヘッダーからふたの後ろ端まで約 6 mm |
| 前の VL53L1X（5〜6 本） | 受けの穴から上へ → バンパー上面を左へ → フランジ左の結束バンド用ブリッジ 2 か所 → 箱の後ろから GPIO ヘッダーへ | 約 27 cm（30 cm のジャンパー線が必要） |
| 後ろの VL53L1X（5〜6 本） | 受けの穴から上へ → Motor HAT の上を通って GPIO ヘッダーへ | 約 15 cm |

- ピン配置と長さはすべて推定。VL53L1X・IMU のピンの位置、LiDAR の USB 変換基板の大きさは実物に合わせて見直す
- バンパーの前面の板は動くが、センサーは固定側にあるので配線は引っ張られない
- 結束バンド用ブリッジは幅 3.6 mm までの結束バンドが通る（`tie_w`）
- DROK の大きさ・部品の高さ・裏のピンの位置は商品画像からの推定。受けに当たる部品があれば `drok_rib_x`（リブの位置）と縁の位置を直す

## 組み立て

1. 天板の前側 4 本のネジを外し、フランジの厚さ（3 mm）ぶん長いネジで箱ごと留め直す
2. バッテリーを、ポートのある短辺を開口側（既定は右）に向けて 2 個重ねて上から入れる（開口側のボスに当たるので、横からは差し込めない）
3. 開口側寄りの左右スロットに面ファスナー（幅 10 mm 程度）か結束バンドを通して、上下 2 個をまとめて固定
4. LiDAR をふたの柱に載せ、ふたの裏から柱の中に M2.5 x 8 mm のネジを通して 4 か所留める（ふたを箱に付ける前に行う）
5. ふたを M3 x 12 mm のネジ 4 本で箱のボスに留める
6. Camera Module 3 Wide を端子を上にして、先にフラットケーブルの 15 ピン側（太いほう）を差してから、`cam_mount.stl` の板の支柱に前から M2 x 6 mm で 4 本留める（ナットで留めるときは M2 x 8〜10 mm にして、ナットを板の裏の六角のくぼみに入れる。ナットとネジの先はふた・箱の逃げ穴に入る）。板の裏をふたの前端の面に当て、左右の耳をふたの前端の柱に M3 x 8 mm で留める。ケーブルを上の表の経路で通し、22 ピン側（細いほう）を Pi の CAM の口へ
   - 2 眼カメラのとき: 2 眼カメラを USB 端子を上にして、`cam_mount.stl` の板の支柱に前から M2 x 6 mm で 4 本留める。板の裏をふたの前端の面に当て、左右の耳をふたの前端の柱に M3 x 8 mm で留める。L 字の USB-C プラグを上から差して後ろへ曲げ、ケーブルを LiDAR の前の柱の間からふたの上の結束バンド用ブリッジ 2 か所（X 77 / Y 166 と、ふたの後ろ端の X 86 / Y 119.4）で留めて Pi の USB へ。`dashboard.yaml` の `rotate_180` を false にする
   - IMU はピン下向き・ピンヘッダーの長辺を右にして、ジャンパー線を差したまま右から斜めに入れ、左（-X）の縁を奥の壁の出っ張りの下に差し込んでから 3 辺の段に載せる。台は LiDAR のヘッドの下なので、LiDAR を付ける前に入れると楽
7. ラズパイ台を天板の後ろ側 4 穴に、フランジと同じく長いネジで留め、Pi 5 を M2.5 のネジかスペーサーで留める
8. DROK を部品面を Pi 側に向けて箱の後ろの棚に立て、中央のリブの穴に結束バンドを通して締める（ふたを付ける前のほうが通しやすい）

9. 上面カバーを、充電口が右（バッテリーのポート側）に来る向きで真上から被せ、左右のフックがカチッと天板の端の裏に掛かるまで押し下げる。外すときは左右の指かけを外へ引きながら持ち上げる

## 上面カバー

天板の上の部品全体を覆う一体のカバー。工具を使わず、左右のフックで天板の端の裏に引っかけて留める。

- 外形: 約 164 x 212 x 88 mm（フックと指かけを含む）。Creality K1C（220 x 220 x 250 mm）で一体で印刷できる。上面を下にして印刷し、サポートは不要（`cover.stl` は X 軸まわりに 180° 回して上面を下にしてある。鏡に写した形ではないので、文字も充電口の位置も組立図と同じ）
- 高さ: 上面の裏が天板から 80 mm、外側は 82.4 mm（Pi の 3 段の上端 54 mm の上に 26 mm）。LiDAR の取付面（90.4 mm）はカバーの上面より 8 mm 上にあり、LiDAR のヘッドは全部カバーの上に出る。取付面より下に出るモーターと基板の部分（26.5 mm）と柱は、カバーの抜きの中に入る
- 付け外し:
  - フック 4 個（左右の Y 54 / 170 mm。後ろは Pi の電源ボタンの穴をよけて天板の後ろの端から 54 mm、前は前の端から 30 mm、幅 12 mm）。両側に 1 mm の切れ目を入れ、下端から 28 mm がたわむ
  - 右前（Y 170 mm）のフックは充電口の下の細い帯（高さ約 7 mm）にあり、たわませる長さが取れないので、切れ目のない固定の爪にした（`cov_hook_fixed`）。付けるときは右側を先に斜めに入れて右前の爪を天板の裏に掛け、そのあと左側を押し下げる。外すときは左の指かけを外へ引いて左側から持ち上げる
  - 爪の上面は平らで、天板の裏（下面から 0.2 mm）に掛かる。下面は斜めなので、押し下げると天板の端に当たって外へ逃げる
  - 外すときは、爪の外側の指かけを外へ引いて持ち上げる
  - 天板の上面には受け（幅 8 mm）が載って高さが決まる。フックの両隣（フックの中心から前後に 12 mm）と中央（Y 100 mm）に置き、爪と受けで天板の端をはさむ。左右とも Y 42 / 66 / 100 / 158 / 182 mm の 5 か所（`cov_stop_y`）。ふたの前後の縁をはさむリブ 4 本で、前後の位置も決まる
- LiDAR: LiDAR の外形（ヘッド、柱 4 本、モーター側）より大きく上面を抜いてある。LiDAR を付けたまま、カバーを真上へ抜ける
- 開けた穴:
  - 充電口（右側面、Y 113〜185 mm、高さ 5〜38 mm）: 箱の右の開口の前にあり、カバーを付けたままバッテリーの USB-C に差せる。ケーブルの出口も兼ねる
  - カメラの窓（前面、Camera Module 3 Wide）: レンズの中心（X 69 mm、高さ 40.4 mm）に、内側 15.6 x 13.0 mm・外側 22.5 x 16.7 mm の、外へ広がる四角い窓（`wcam_win()`）。画角（横 102°・縦 67°）の線より片側 4° 外、レンズのまわりに 1.5 mm のすき間。レンズの先は壁の内側より奥なので、カバーを真上へ抜ける。窓の下に 2 本のスリット（高さ 16〜19 / 23〜26 mm）
  - 2 眼カメラの窓（前面、`front_cam="stereo"` のとき、`cov_scam_slot()`。左右のレンズごと、X 28.5〜49.5 mm と 88.5〜109.5 mm、壁の下の端から高さ 50.9 mm まで、上は半円）: レンズ（Ø18 mm）より片側 1.5 mm 広い。レンズの先はカバーの前の壁より 13.3 mm 前に出るので、窓を下の端から切り込み、カバーを真上へ抜けるようにした。左右の窓の間の 39 mm（基板の中央・USB 端子・チップ）は壁で守る
  - バッテリーの残量表示の窓（上面、LiDAR の抜きの右隣）: 上のバッテリーの表示（ポートの短辺から 7〜20 mm、ロゴの面でポートを上にしたときの右の長辺から 9〜21 mm。`bat_disp`）の真上に、ふたは 15 × 14 mm、カバーは 17 × 16 mm（縁は 1 mm の面取り）で開けた。表示からカバーの上面まで約 47 mm あるので、ほぼ真上から見る（斜めからだと窓のふちで一部が隠れる）
  - 通気口（Pi の上、六角 Ø4.8 を約 90 個）
  - Pi 5 の電源ボタンの穴（左の壁、Y 22〜40 mm・天板から高さ 7〜18 mm、角の丸い 18 x 11 mm）。カバーの外の面からボタンまで約 7 mm なので、指先か、ペンの後ろなど細い棒で押す。ボタンの位置は Pi 5 の機械図面に寸法がないため、「左の短辺の、USB-C の長辺から 0〜18 mm」と広めに見込んだ（`pi_btn_y`、`pi_btn_z`）。印刷したら、穴からボタンが見えるか確かめる
  - 前後の壁の下端は天板から 11 mm。バンパーの上面（7 mm）とのあいだを VL53L1X の線が通る
- 見た目: 上面の角を面取りし、後ろを斜めに落とした形。手で触る縁（外側の角と稜線、壁の下端、充電口のふち）は 1 mm の面取り（`cov_edge`。外形の大きさは変わらない）。前面のカメラの窓の下に 2 本のスリット、上面の右前に「AI-CAR」の文字（深さ 0.8 mm）
- ぶつからないこと: 天板・箱・ふた・ラズパイ台・バンパー・LiDAR・2 眼カメラ・IMU・DROK・センサー・Pi・バッテリーの外形と、付けた状態で重ならないこと、真上へ抜くときに当たらないこと（フックの爪は除く）を OpenSCAD で確かめた

## 変更しやすいパラメーター

- `open_end`: バッテリー出し入れ側（`"right"` / `"left"`）
- `clr` / `clr_x` / `wall_y`: バッテリーとのすき間（前後の片側 0.4 mm / 左右の片側 0.3 mm）と前後の壁の厚さ（前後のすき間を変えるときは、外形 75.2 mm を保つよう一緒に変える）
- `lidar_tower_h`: LiDAR の高さ
- `lidar_motor_front`: LiDAR のモーター側を前に向けるか
- `lidar_dx`: LiDAR の横位置（2 眼カメラは LiDAR の回転中心に左右をそろえるので一緒に動く。ROS の `camera_offset_*` と URDF も直す）
- `front_cam`: 前カメラ（`"wide"` = Camera Module 3 Wide / `"stereo"` = USB 2 眼カメラ）。板とカバーの窓が切り替わる
- `wcam_*`: Camera Module 3 Wide の基板・穴・レンズ・裏の端子の寸法と、支柱の高さ（`wcam_so`）、カバーの窓のすき間（`wcam_win_clr`、`wcam_win_deg`）
- `scam_board`、`scam_lens_*`、`scam_hole_in`、`scam_back_h`、`scam_usb_room`: 2 眼カメラの基板・レンズ・ねじ穴・裏の部品の寸法と、USB のプラグの分の高さ（板の形とカバーの窓が決まる）
- `imu_c`: IMU の台の位置（ふたの上。LiDAR の USB 変換基板・カメラのケーブル・柱・残量表示の窓をよける）
- `bat_disp`: バッテリーの残量表示の位置（ふたとカバーの窓の位置が決まる）
- `screw_mode`（`"tap"` / `"insert"`）、`tap_d`、`insert_d`、`mount_hole_d`: ネジ穴の形と径
- `pi_btn_y`、`pi_btn_z`: カバーの左の壁の電源ボタンの穴の範囲（Pi の基板から。ボタンが穴の端にかかるときに変える）
- `cov_hook_lip`、`cov_hook_root`: カバーのフックの掛かり（深さ）と、たわむ長さ（きつい・ゆるいときに変える）
- `cov_chg`: カバーの充電口の位置と大きさ（バッテリーの USB-C の口に合わせる）

STL の再生成:

```
openscad -D 'part="box"' -o box.stl battery_lidar_mount.scad
openscad -D 'part="lid"' -o lid.stl battery_lidar_mount.scad
openscad -D 'part="pi_base"' -o pi_base.stl battery_lidar_mount.scad
openscad -D 'part="cam_mount"' -o cam_mount.stl battery_lidar_mount.scad
openscad -D 'part="cover"' -o cover.stl battery_lidar_mount.scad
openscad -D 'part="cam_mount"' -D 'front_cam="stereo"' -o cam_mount_stereo.stl battery_lidar_mount.scad
openscad -D 'part="cover"' -D 'front_cam="stereo"' -o cover_stereo.stl battery_lidar_mount.scad
```

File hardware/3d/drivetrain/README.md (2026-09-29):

# AI-CAR 駆動系の参考モデル（drivetrain）

天板の下に付いている購入品（印刷しない）を、ダッシュボードの 3D プリントタブの組み立て図 3 つに重ねて表示するための形です。

| STL | 中身 | 表示の色 |
|---|---|---|
| `wheels.stl` | メカナムホイール ×4（直径 80.59 mm、幅 39.1 mm、ローラー 8 個・45°。左前と右後ろ、右前と左後ろが同じ向き） | 濃い灰 |
| `motors.stl` | 520 エンコーダー付きモーター ×4（全長 58 mm、ギア箱 Ø37 × 24 mm、モーター Ø32.8 mm、軸 Ø4）とカップリング | 銀 |
| `holders.stl` | 37 mm モーターの台 ×4（L 字、板厚 2 mm、底 42 × 40 mm、立ち上がり 46 mm） | 黒 |

座標は天板と同じです（X 左右: 天板の左端 0、Y 前後: 天板の後端 0・+Y が前、Z: 天板の上面 0）。そのまま組み立て図に置けます。

## 配置の出どころ

- モーターの台は天板の下面に付き、底の穴は天板の穴（X 12 / 36 mm・Y 37 / 67 mm、OSOYOO の 1st_layer.dwg）に合わせています。軸は台の底から 27 mm 下（天板の上面から 29 mm 下）、車軸は天板の前後の端から 52 mm
- モーターは台の立ち上がりの内側に付き、天板の左右の端から 4.5〜62.5 mm（左右のモーターの間は約 29 mm）
- 車輪の内側の面は、カバーの左右の壁の外側から 4 mm（`wheel_in`、試験台と同じ仮の値。カップリングの長さが資料にない）
- 図面から計算すると、床から天板の下面までは 67.3 mm です（試験台で使っている実測の 70 mm とは 2.7 mm 違います）

寸法の資料は `hardware/3d/test_stand/README.md` の「車輪と車軸の寸法の出どころ」と同じ OSOYOO の図面です。ローラーの太さとカップリングの太さは資料にないので、見た目の値です。

## 作り直し

```bash
cd hardware/3d/drivetrain
for p in wheels motors holders; do openscad --export-format binstl -D "part=\"$p\"" -o $p.stl drivetrain.scad; done
```

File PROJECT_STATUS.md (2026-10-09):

# PROJECT_STATUS.md

## 最終更新
- 更新日: 2026/09/19
- 更新概要: 2026/09/25、プロジェクト説明に「3D プリント」タブ（STL ダウンロード・三面図・立体図・3D 表示・印刷設定・ネジ・組み立て手順）と `GET /print3d/{file}` を追加。以前: 2026/09/25、Motor HAT の出力故障を切り分け、交換を決定（既知の問題に記録）。Motor HAT 配線表に 1 本ごとの「備考」列を追加。エンコーダー VCC / GND の接続先表記を「Motor HAT (3V3 power)」「Motor HAT (Ground)」に統一（ダッシュボード・BOM・設定コメント）。以前: 2026/09/23、モーター 6 本の配線色をエンコーダー基板のコネクタ印字に基づき修正（Motor+ 黒 / Motor− 赤 / VCC 白 / GND 黄 / Encoder A 橙 / Encoder B 緑）。`motor_hat.yaml`・`gpio_pins.yaml`・BOM を更新。以前: 2026/09/23、エンコーダー基板印字（M+ / M− / VCC / GND / S1 / S2）から読み取ったモーター 6 本の配線色を確定（Motor+ 緑 / Motor− 橙 / VCC 黄 / GND 白 / Encoder A 赤 / Encoder B 黒）。`motor_hat.yaml`・`gpio_pins.yaml`・BOM を更新、接続図・一覧表は再読込で反映。以前: CPU 使用率 20% 以下を目標に、カメラ取り込み 15fps、推論 5Hz、テレメトリ 5Hz、LiDAR 点群 最大360点、IMU 20Hz、autonomy / joy 10Hz、液晶 2Hzへ周期を見直し。実機測定でダッシュボード CPU は概ね 18〜21%まで低下。以前:
- 更新概要: プロジェクト説明モーダル（7タブ）と `/api/architecture` を追加。GPIO 40 ピン / Motor HAT 接続図カードはメイン画面からハードウェア構成タブへ移動、LiDAR 表示の距離リングに数値ラベルを追加。以前: 状態表示器を TM1637 7 セグから ZJY-IPS130-V2.0（ST7789 1.3 インチ 240×240 IPS 液晶、SPI0、7 ピン CS なし）へ変更。新規 `lcd_display_node`（spidev + libgpiod + Pillow）が運転モード / 自律行動 / 前方距離 / 障害物 / 電圧 / CPU 温度 / パッド接続 / IP を描画し、従来と同じコードを `/display_state` に publish。配線: VCC pin17 赤、GND pin20 黒、SCL pin23(GPIO11) 橙、SDA pin19(GPIO10) 黄、RES pin18(GPIO24) 緑、DC pin22(GPIO25) 青、BLK pin16(GPIO23) 紫。launch 既定を `use_lcd_display=true` / `use_seg_display=false` に変更（GPIO23/24 共用のため同時起動不可）。`gpio_pins.yaml`・BOM・README を更新。以前: 運転モード管理 `drive_mode_node`（手動 / 自動 / 停止、`/cmd_vel` を発行する唯一のノード）と Level 1 自律走行 `autonomy_node`（LiDAR 反応型、`/cmd_vel_auto`）を追加。`dashboard_node` の手動指令出力を `/cmd_vel_manual` に変更し、`GET/POST /api/drive_mode` とテレメトリ `drive_mode` / `autonomy` を追加。ゲームパッドは START 長押し（2 秒）で手動 ⇄ 自動、BACK（自動中は B も）で停止。画面に運転モードバッジ・3 ボタン・自律走行カードを追加、7 セグに `AUto` / `StoP` を追加。以前: Motor HAT 接続図・一覧表を「1 モーター 6 本（Motor+ / Motor− / VCC / GND / Encoder A / Encoder B）」をすべて明示する形に変更（`GET /api/motor_hat` の各モーターに `wires` 6 件、`encoder` に `vcc` / `gnd` を追加、GND はモーターごとに pin 30/34/39/25 を割り当て、VCC は pin 17 共通。VCC / GND は Motor HAT 上の 3V3 / GND ピンに接続する表記に変更し、Pi GPIO ヘッダー表では該当ピンを空きとして表示）。表示から「520 モーター」の文言を削除し、ラベルは「M1 前左 Encoder A」形式。以前: モーターの配線色をメーカー資料に合わせて確定（赤 Motor+ / 白 Motor− / 青 VCC / GND 黒 / 緑 Encoder A / 黄 Encoder B）し、車輪表記を進行方向基準の「M1 前左」形式（前左 / 前右 / 後左 / 後右）に統一。接続図・一覧表・BOM・GPIO 表の表記を Motor+ / Motor− / Encoder A / B に揃えた。以前: OSOYOO 520 モーター内蔵エンコーダー（A/B 相）の Pi GPIO 直結割り付けを追加（`motor_hat.yaml` の `encoder`、`gpio_pins.yaml`。M1: 29/31、M2: 33/35、M3: 37/32、M4: 36/38、VCC 3V3 pin17、GND 30/34/39/25）。Motor HAT 接続図・一覧表・GPIO ヘッダー図にエンコーダーピンを表示。以前: ダッシュボードに「Motor HAT 接続図」カード（Adafruit Motor HAT の M1〜M4 と車輪位置の割り付け・配線図・一覧表）を追加。割り付けは `config/motor_hat.yaml`（M1=前左 / M2=前右 / M3=後左 / M4=後右、右側は `reversed: true`）で編集し `GET /api/motor_hat` で取得。以前: TM1637 4桁7セグメントLED用 `seg_display_node`（`/display_state`）と GY-BNO055 用 `imu_node`（I2C 0x29、`/imu/data`）を追加。Logitech F710 ゲームパッドによる手動操作（`joy_teleop_node`）を追加。以前: ダッシュボードに Raspberry Pi 5 の GPIO 40 ピンヘッダー図（横向き、上段 2〜40 / 下段 1〜39）と 40 ピン一覧表（使用中・配線色・接続先・信号）を追加。配線は `config/gpio_pins.yaml` で編集、`GET /api/gpio` で取得。以前: ダッシュボードの systemd 自動起動サービスと respawn 対応を追記。カメラと LiDAR のカードを先頭に移動し横幅を2列分に拡大。LiDAR の取り付け向きを 180° 補正し、カメラ検出物体の距離推定をクラスタ中央値に変更。CPU カードに入力電圧・入力電流と低電圧・スロットリング警告を追加し、CPU / AI HAT+ カードの注記行を削除。CPU カードのロードアベレージを削除し PD 対応（5A）の 〇 / × 表示に変更。
- 更新担当: Devin

## システム構成
- 実行環境: Raspberry Pi 5
- ROS: ROS2 Jazzy（ros-base）
- ナビゲーション: Nav2（未導入）
- センサー: LiDAR（RPLIDAR A1M8）、カメラ（v3）、IMU（BNO055）
- Web: FastAPI + uvicorn
- 開発環境: VS Code Remote-SSH
- AI: Cline + LM Studio + DeepSeek 32B Q4_K_M

## 実装済み機能
- ai_car_description
  - URDF/Xacro（`urdf/ai_car.xacro`）: base_footprint / base_link / メカナム4輪 / laser / camera_link / camera_optical_frame / imu_link（計10リンク）。laser と camera_link は 3D マウントの CAD の位置
  - Launch（`launch/view_robot.launch.py`）: robot_state_publisher、joint_state_publisher、use_gui / use_rviz / use_sim_time 引数
  - RViz2設定（`rviz/ai_car.rviz`）: RobotModel / TF / LaserScan
- ai_car_web
  - `dashboard_node`: FastAPI サーバー（別スレッド）+ rclpy ノード
  - 「プロジェクト説明」ボタンと8タブの全画面モーダルを追加（「3D プリント」タブは STL ダウンロード・三面図・立体図・ドラッグで回せる 3D 表示・印刷設定・組み立て手順）。`architecture.yaml` と `/api/architecture` から構成を表示し、`dashboard.yaml` の実値（秘密値はマスク）と実機の生存ノード / Topic を反映
  - Publish: `/cmd_vel_manual`（geometry_msgs/Twist、手動指令。`/cmd_vel` は `drive_mode_node` が発行）、`/drive_mode_request`、`~/status`
  - `drive_mode_node`（運転モード管理）: `/cmd_vel_manual`（Web + ゲームパッド）と `/cmd_vel_auto`（自律走行）のどちらか一方だけを `/cmd_vel` に中継する。モードは manual / auto / stop（起動時 manual）。状態は `/drive_mode`（JSON, transient local, 5Hz）、切替要求は `/drive_mode_request`（JSON `{mode: manual|auto|stop|toggle, source}`）。安全機構: 自動へ入る条件（`/obstacle_status` が新鮮で stop / unknown でない・ゲームパッド接続中・スティック中立・`/cmd_vel_auto` 生存）を満たさないと拒否（`last_reject` に理由）、自動指令が `auto_timeout` 0.5 秒途絶／ゲームパッド切断／障害物判定途絶で STOP、自動中に手動指令を検出すると手動へ復帰（`manual_override`）、モード遷移時はゼロ速度を publish、最終段で障害物 stop 判定中・LiDAR データなし（unknown）・判定の途絶中の前進を 0 にする（`obstacle_guard`、手動も）。launch 引数 `use_drive_mode`
  - `autonomy_node`（Level 1 自律走行・LiDAR 反応型）: `/scan` を前 / 左 / 右 / 後セクターに分けて最短距離を求め、前進（0.15 m/s）→ 0.8 m 以内で減速（0.08 m/s、空いている側へ緩く曲がる）→ 0.35 m 以内で空いている側へその場旋回（0.6 rad/s、前方 0.9 m 以上空くまで）→ 前進を繰り返す。前後左右とも 0.25 m 以内なら後退。LiDAR が 1 秒以上途絶えると停止。`/cmd_vel_auto` に 10Hz で常時 publish（AUTO 以外はゼロ速度で待機）、状態は `/autonomy_status`（JSON: behavior / sectors / cmd）。地図・自己位置は使わない。launch 引数 `use_autonomy`
  - 運転モード UI: 手動操作カード上部にモードバッジ（手動 / 自動 / 停止）と 3 ボタン（`POST /api/drive_mode`）、拒否理由表示。自律走行カードに行動・各方向距離・自動指令・`/cmd_vel` 出力を表示
  - Subscribe: `/scan`、`/imu/data`、`/odom`、`/camera/image_raw/compressed`
  - `imu_node`: GY-BNO055（I2C バス1、アドレス0x29）を読み取り、`/imu/data`（sensor_msgs/Imu）を20Hzでpublish。パラメータは `i2c_bus` / `i2c_address` / `frame_id` / `imu_topic` / `publish_rate`
  - REST: `GET /api/status`、`POST /api/cmd_vel`、`POST /api/stop`、`GET /api/camera/snapshot`、`GET /api/camera/stream`（MJPEG）、WebSocket `/ws`（テレメトリ配信）
  - カメラカード: MJPEG 映像と受信フレーム数・最終受信時刻を表示（未受信時は待機表示）
  - LiDAR カード: `/scan` の360度スキャンを上面視の点群マップ（Canvas、最大720点（`scan_max_points`）、表示範囲は 3 m で固定、3 m より遠い点は描かない）として描画。カード順は カメラ → LiDAR → CPU → AI HAT+ で、カメラと LiDAR は横幅 2 列分（狭い画面では 1 列）
  - LiDAR ノード: `rplidar_ros`（`rplidar_composition`）を `dashboard.launch.py` の `use_lidar` で起動。ポートは by-id パス、115200bps、`frame_id: laser`。`lidar_watchdog_node` が `/scan` の 3 秒途絶で rplidar を止め、respawn で起動し直させる（USB が抜けてつながり直すと、rplidar は `/scan` を出さなくなるため）。2 回続けて戻らなければ LiDAR の USB をつなぎ直す（電池の電圧低下の後に CP2102 が返事をしなくなったとき用）。4 回で USB の電気を 3 秒切って入れ直し（`ai-car-usb-power-cycle`、uhubctl、ゲームパッドも数秒切れる）、7 回でラズパイを再起動する（この起動で `/scan` が来ていて、起動から 30 分たっているときだけ）
  - カメラノード: `dashboard.launch.py` の `use_camera` で起動。`camera_type:=stereo`（既定）は USB 2 眼カメラの `stereo_camera_node`、`camera_type:=picam` は `camera_ros`（libcamera）。`~/opt/rpicam` の Raspberry Pi 版 libcamera を `LD_LIBRARY_PATH` に自動追加
  - 障害物判定ノード（`perception_node`）: LiDAR を主として前方 ±30° を左/中央/右セクターで評価し、停止 0.35m / 減速 0.8m で 停止・減速・安全・不明 を判定。カメラ画像は AI HAT+（Hailo-8）で 1 眼の奥行きの AI（SC-Depth v3）だけを動かし、床から出っぱった低い物を表示する（2026/10/09 から物の名前を当てる YOLO `yolov8m.hef` は `hef_path: ""` で止めている。`hef_path` に入れれば、検出枠を履歴3中2回で確認して物体名を補助情報として付ける）。結果は `/obstacle_status`（JSON, 5Hz）
  - 検出物体の距離: 枠の真ん中（縦横の半分）にかかる 2 眼のマス（`/stereo/depth_grid`、左目の画像の 32×18、4 m まで）が 3 割以上測れていれば、その手前のまとまりの中央値を 2 眼の距離として使う（画面に「（2眼）」）。測れない所（左はし約 42° より左・模様のない面など）は次の LiDAR の距離（「（LiDAR）」）。LiDAR は床から 17.5 cm の 1 本の線なので、高い所の物（テレビなど）では手前の低い物の距離になることがある。LiDAR の距離: 画像の横位置を `camera_hfov_deg`（66°）で方位角に変換し、LiDAR の同方位の距離を採用（LiDAR の点は、LiDAR の中心から見たカメラの位置 `camera_offset_x_m` 0.079 / `camera_offset_y_m` 0.030（前 79 mm・左 30 mm。2 眼カメラの左目のレンズの先、CAD 値）に移し、カメラから見た方位で照合する。距離はカメラのレンズから前方への距離）。カメラ映像に検出枠と距離を重畳し（枠の色は LiDAR の図の点と同じ距離の色: `danger_distance` 以内 赤 #ff5c6c / 停止距離以内 橙 #ff8a4c / 減速距離以内 黄 #f5b942 / それより遠い 水色 #35d6ff、距離不明 灰色。1 眼・2 眼の低い物の枠も同じ）、LiDAR 点群マップでは前方 ±30°（`front_angle_deg` 60°）内かつ 0.3m 以内の点を赤点で表示。点群マップには前方／後方／左／右のラベルを表示（上＝前方）。方位角範囲内の点は距離でクラスタリングし（`cluster_gap` 0.25m）、最も手前のまとまりの中央値を採用する。スキャンが `scan_max_age`（1秒）より古い場合は距離を出さない。LiDAR の取り付け向きは `scan_angle_offset_deg` で補正する。画面の「前方」は前方カメラの正面とし、カメラの画面の真ん中に置いたボトルが LiDAR で右 4°・0.47 m に見えたことから −1.7° とした（2026/10 実測。`dashboard_node`・`perception_node`・`autonomy_node` と URDF の `laser` の向きで同じ値）
  - 人・動物の早めの減速・停止: カメラの前方（画面の中央半分）に写った人・犬・猫・鳥（`living_labels`）の LiDAR 距離が 1.5 m（`living_slow_distance`）以内で減速、0.6 m（`living_stop_distance`）以内で停止と判定し、`/obstacle_status` の `living` に出す。`living_guard: true` のときだけ LiDAR の判定より厳しい方を `level`・`speed_scale` に使う（既定は false で表示のみ）
  - 2 眼の距離: `stereo_depth_node` が `/stereo/pair_gray`（`stereo_camera_node` が左右を 320×180 の白黒にして 3 Hz で出す）を受け、`stereo_calib.yaml` で平行化して SGBM で距離を出す。通り道（中心 `corridor_center_y_m` −0.038 m・片側 0.15 m）の中で、床より 0.02〜0.6 m 高い点（10 点以上）のうち近いほうから 5% の距離を「いちばん近い物」として `/stereo/depth_status` に出す（2 m まで）。測れる近さは約 0.10 m から（視差 64 px、左はし約 42° より左は測れない。1 回 約 25 ms）。床より 2 cm 以上高い点を物とみなす。0.6 m より近い物は、画像の上でつながりごとに分けて `objects`（近い順に 5 個まで）にも出し、映像に 1 個ずつ枠を出す。ダッシュボードのカメラカードの「2眼の距離」の行に出し、「距離の画像」ボタンで映像を距離の色（近い = 赤、遠い = 青、測れない = 黒、通り道の物 = 白っぽい）に切り替える（`GET /api/camera/depth_stream`）。`perception_node` はいちばん近い物の方位（`bearing_min_deg`〜`bearing_max_deg`）の LiDAR の距離がそれより 0.15 m 以上遠い（または無い）と「低い障害物」とし、0.8 m で減速、0.45 m で停止と判定して `/obstacle_status` の `stereo` に出す（`stereo_guard: true` のときだけ速度に反映。dashboard.yaml は true で、低い物で `speed_scale` を 0.5 / 0 にする。0.6 m より近い所の「いちばん近い物」は `objects` に残ったまとまり（10 点以上・横幅 2 cm 以上）から選ぶ）。「2眼の距離」の行の後ろに「LiDAR にも見える」「→ 減速（表示のみ）」などと出す
  - システム構成（プロジェクト説明の「システム構成」タブ、`architecture.yaml` の `system`）: AI-CAR・Jetson Orin Nano Super・M5 スタックちゃんの役割とやりとり（① 画像 ② 名前・位置は稼働中、スタックちゃんとの声も稼働中、スタックちゃんのカメラの映像も稼働中、声の命令は予定）を図と表で出す
  - 液晶（ZJY-IPS130-V2.0、ST7789）は 2026/10 に取り外し、`lcd_display_node`・launch の `use_lcd_display`・`dashboard.yaml` の設定・`gpio_pins.yaml` の配線（pin 16/17/18/19/20/22/23）を消した。旧 TM1637 の `seg_display_node` は残っている（既定では起動しない）
  - Jetson の物体検出（表示のみ）: Jetson Orin Nano Super の `jetson/owl_detector`（NanoOWL、`jetson-owl.service`）が AI-CAR のカメラ画像から `prompts.json` の物（段ボール箱・袋など）を探し、`POST /api/jetson/detections` → `/jetson_detections` → `perception_node` が LiDAR の距離を付けて `/obstacle_status` の `jetson` に出す。2 秒以上届かないと「未接続」。速度制限には使わない。LiDAR の図にもカメラの見える範囲（扇形）と物の位置を点で重ねる（名前・距離の吹き出しは出さない）。2 眼の物（`/obstacle_status.stereo.objects`）も、色を距離、直径を横幅の 2 倍にした白ふちの点で描く
  - Jetson の状態（表示のみ）: Jetson の `jetson/status_reporter`（`jetson-status.service`）が 1 秒ごとに温度・CPU / GPU の使用率・メモリ・スワップ・消費電力・AI の部品（whisper-server・Ollama・Kokoro。声→文字・文字→声は仕組みの名前（例: whisper.cpp small（GPU）・Kokoro TTS 1.0.0）、会話の AI はモデル名と GPU / CPU で動く割合も）・セキュリティ更新の残り・再起動が必要か・IP アドレスを `POST /api/jetson/status` へ送り、ダッシュボードの「Jetson Orin Nano Super — AI 担当」カード（「Raspberry Pi 5 — CPU」の右）に出す。5 秒以上届かないと「未接続」。速度や安全の判定には使わない。NanoOWL は 2026/10 からメモリを空けるため止めている（電源モード・ファン・NanoOWL の値も送るが、カードには出さない）
  - スタックちゃんのカード（表示のみ）: ダッシュボードの「M5 スタックちゃん（CoreS3）」カード（Jetson カードの下）。Jetson の `stackchan_bridge` の `GET /status`（8003）を `GET /api/stackchan/status`（API トークン）で 2 秒ごとに取って、今の様子（聞いている・呼びかけ待ち・考えている・話している・待ち受け）に合わせた顔、最後の会話（聞き取り・返事・かかった時間）、IP アドレス・ファームウェアの版・会話の数・使っている仕組みを出す。写真（320×240）は、スタックちゃんに「撮影して」と言って撮ったものを `GET /api/stackchan/photo.jpg` で出す（カードには撮るボタンを置かない）。行き先は `stackchan_bridge_url`、空なら Jetson が送ってくる IP アドレス（Tailscale を先に）の 8003。ネットのときもローカルのときも、つながったら「呼びかけ待ち」で、「スタックちゃん」と呼ぶと会話モードになり、最後に話してから 30 秒だまると「じゃあ、またね。」と言って呼びかけ待ちにもどる（`jetson/stackchan_bridge/README.md`「呼びかけ」）。テレビの声で起きないように、呼びかけは文の頭で名前を呼んだときだけ（whisper の音の注釈・文の途中・名前の話題・`--prompt` の返しはとらない）。走行・安全には使わない
  - スタックちゃんの会話: 純正ファームウェア（1.5.1）の AI Agent を、Jetson の `jetson/stackchan_bridge`（`jetson-stackchan.service`、OTA 8003・WebSocket 8000）経由で whisper-server・Ollama qwen2.5:3b・Kokoro jf_alpha につなぐ。パソコン（WSL の Ubuntu、RTX 4080 SUPER、Tailscale の taka3-wsl）が動いているあいだは、聞き取りを whisper large-v3、返事を qwen2.5:14b でパソコンにさせ、止まっていれば Jetson にもどす（`jetson/stackchan_bridge/README.md`「パソコンで聞き取りと返事」）。ダッシュボードの Jetson のカードの「動かす所」（Jetson / MyPC）で、どちらでするかを選べる（`POST /api/stackchan/backend`）。ファームウェアは行き先（`CONFIG_OTA_URL`）と自動更新をやめるパッチだけを変える。純正の全部（16 MB）は Jetson の `~/stackchan_backup/` にある。走行・安全には使わない
  - Jetson の更新ボタン: Jetson カードの「Jetson を更新」（確認の画面あり、API トークンが必要）。次の状態の返事で伝え、`jetson-upgrade.service`（`jetson-upgrade.sh`）が NVIDIA の部品（JetPack）以外を更新する。試しに動かして NVIDIA の部品が変わるか消える部品があるときはやめる。「全部」の数も NVIDIA の部品を除いた数
  - 再起動ボタン: ラズパイと Jetson のカードの「再起動」ボタン（確認の画面あり、API トークンが必要）。ラズパイは走行中・自動運転中は断り、押してから 10 秒後に再起動する（そのあいだに押した Jetson の再起動も受け付け、伝え終わってから再起動する）。Jetson は次の状態の返事で伝え、`jetson_status.py` が再起動する。「電源を切る」ボタンも同じしくみ（`POST /api/system/poweroff`・`/api/jetson/poweroff`、ダッシュボードからは入れ直せないので、本体の電源ボタンか電源のつなぎ直しで入れる）。どちらも `systemctl reboot` と `systemctl poweroff` だけをパスワードなしで許す sudoers が要る
  - つながりの印: カメラ・LiDAR・Raspberry Pi 5 — CPU・AI HAT+・IMU・落下防止センサー・Jetson のカードのタイトルの横に「接続中」などを出す（LiDAR・IMU は 2 秒、`/system_status` は 3 秒、Jetson は 5 秒届かないと途絶 / 未接続）
  - 更新の進み具合: ボタンの更新のあいだ「更新中 45 %」のように出す（ダウンロード 0〜30 %、インストール 30〜100 %。`/run/ai-car-upgrade.progress`・`/run/jetson-upgrade.progress`）
  - ラズパイの更新: 「Raspberry Pi 5 — CPU」カードに「セキュリティ更新」（`apt-check`、1 時間に 1 回とボタンの更新のあと）「再起動」（必要 / いらない）と「ラズパイを更新」ボタン（確認の画面あり、API トークンが必要、走行中・自動運転中は断る）。ボタンは `ai-car-upgrade.service`（`systemd/ai-car-upgrade.sh`、ROS 2 も含めて更新、消える部品があるときはやめる）を始める。自動のセキュリティ更新は Ubuntu の unattended-upgrades（自動の再起動なし）
  - SLAM（地図と自己位置）: `use_slam:=true` で `slam_toolbox` を起動し、ダッシュボードの「地図と自己位置（SLAM）」に地図と自己位置を出す。地図は `~/AI-CAR_ws/maps` に保存できる。車輪のオドメトリが無いので位置はスキャンの照合だけで出す（ゆっくり動かす）。既定は起動しない。自律走行にはまだ使わない
  - サーマル制御: CPU 70℃ / AI HAT+ 75℃ で推論レート 40%、CPU 78℃ / AI HAT+ 85℃ で推論停止（LiDAR 判定は継続）。`dashboard_node` は `speed_scale` を前進指令に適用する（`obstacle_guard`）
  - 画面（`static/index.html`）: 手動操作カードは LiDAR カードの直下（4 列固定グリッド、幅 2 列分）に配置。メカナム方向操作（前後・平行移動・旋回）、出力ゲイン、テレメトリ表示
  - 安全機構: `cmd_timeout`（既定0.7秒）無指令で自動停止
  - ゲームパッド手動操作（`joy_teleop_node`）: Logitech F710（XInput モード、`/dev/input/js0`）を Linux joystick API で直接読み（追加の Python 依存なし）、正規化済み Twist を `/joy_cmd` に 10Hz で publish。`dashboard_node` が `/joy_cmd` を購読して Web 操作と同じ `publish_cmd_vel()` 経路で `/cmd_vel` に変換するため、最大速度・障害物ガード（減速／停止）・`cmd_timeout` 停止が同様に適用される。割り当て: 左スティック上下=前後、左スティック左右=平行移動、右スティック左右=旋回、十字キー=前後・平行移動（デジタル）、RB=全速（通常は `speed_scale` 0.5）、B=停止（押している間。自動中は STOP モード要求）、START 長押し 2 秒=手動 ⇄ 自動、BACK=STOP モード、`button_enable` でデッドマンボタンも設定可（既定は無効）。F710 未接続でも起動し、抜き差しを検出して再接続（切断時は指令を出さない）。画面の手動操作カードに接続状態（未接続／接続中／操作中）を表示。launch 引数 `use_joy` で無効化可
  - `seg_display_node`（旧表示器、既定では起動しない）: TM1637 4桁7セグメントLEDを libgpiod で駆動し、`/system_status`・`/obstacle_status`・`/joy_cmd`・`/cmd_vel` と `/drive_mode` から状態を判定して `/display_state`（std_msgs/String）へ publish。表示: boot / rdy / HAnd / AUto / StoP / ObSt / SLo / LoU / Err。`use_seg_display` で無効化可
  - パラメータ: `config/dashboard.yaml`（host/port/各トピック名/最大速度/タイムアウト/配信レート）
  - 自動起動: `systemd/ai-car-dashboard.service`（`install_service.sh` で登録、`Restart=always`、USB デバイス待ちで起動を10秒遅延）。カメラ / LiDAR ノードは launch 側で `respawn`
  - 自動起動: `systemd/ai-car-dashboard.service`（`install_service.sh` で登録、`Restart=always`、USB デバイス待ちで起動を10秒遅延）。カメラ / LiDAR / IMU ノードは launch 側で `respawn`
  - `system_monitor_node`: Raspberry Pi 5 / AI HAT+ の状態監視（読み取りのみ）
    - Publish: `/system_status`（std_msgs/String, JSON、1Hz。IP アドレス `ips` は 30 秒ごとに調べる）
    - 取得内容: CPU使用率（全体・コア別）・クロック・温度・ロードアベレージ、メモリ/Swap/ディスク、PMIC レール別電圧・電流・電力、スロットリング状態、Hailo-8 検出状態
    - パラメータ: `publish_rate` / `topic` / `enable_pmic` / `enable_hailo`
    - 依存: `psutil`、`vcgencmd`、`lspci`、`hailortcli`（あれば利用）
  - GPIO 40 ピンヘッダーカード（プロジェクト説明「ハードウェア構成」タブ内「配線詳細」に表示）: `ai_car_web/gpio_pinout.py` の固定ピン定義（物理番号・名称・BCM・種別）と `config/gpio_pins.yaml` の配線定義（`pins` / `device` / `signal` / `color` / `note`）を結合し `GET /api/gpio` で返す。画面は SVG のヘッダー図（種別ごとの色、使用中ピンは緑の外枠、配線色バー、ホバーで接続先表示）と一覧表（ピン / 名称 / BCM / 使用 / 配線色 / 接続先 / 信号・備考）。同一ピンへの複数接続（I2C バス共有）は「/」区切りで併記。パラメータ `gpio_config`（空なら share 内の `gpio_pins.yaml`）。YAML 編集後は `dashboard_node` 再起動で反映
  - Motor HAT 接続図カード（同じく「配線詳細」に表示）: `ai_car_web/motor_hat.py` が `config/motor_hat.yaml` の割り付け（`channel` / `wheel` / `reversed` / `colors` / `note`）に端子ごとの固定情報（PCA9685 の PWM / IN1 / IN2 チャンネル、TB6612 ブリッジ）を重ねて `GET /api/motor_hat` で返す。割り付け: M1=前左（front_left）/ M2=前右（front_right）/ M3=後左（rear_left）/ M4=後右（rear_right）。右側 2 輪は左右対称取り付けのため `reversed: true`（モーター制御ノードで符号反転する前提）。画面は上面図の SVG（前方が上、中央に HAT の端子台 M1 M2 | +− | M3 M4、四隅に車輪、端子→車輪の配線を +/− の配線色で描画、電源端子→12V 系統）と一覧表（端子 / 車輪 / 回転 / 配線色 / PCA9685 ch / ブリッジ / 備考）。端子・車輪の重複や未割り付けは警告表示。各モーターの `encoder`（`a_pin` / `b_pin` / `colors`）と `hat.encoder`（`vcc_pin` / `gnd_pins`）で 520 モーターエンコーダーの Pi 直結ピンを定義し、BCM 番号へ解決・非 GPIO ピン・I2C/ID ピン・ピン重複・VCC が 3V3 以外を警告。接続図は車輪ごとに「M1 前左」＋ 6 本の線（名称・配線色・接続先）を列挙し、一覧表は 1 線 1 行（モーター / 線番号 / ピン名称 / 配線色 / 接続先 / 回転・ドライバ・備考）。パラメータ `motor_hat_config`（空なら share 内の `motor_hat.yaml`）

## 現在作業中

## 未実装機能
- モーター制御ノード（Adafruit Motor HAT / メカナム逆運動学。`/cmd_vel` を購読する）
- エンコーダー読み取り・オドメトリ発行
- SLAM（slam_toolbox）
- Level 2 自律走行（Nav2 による地図ベースのナビゲーション）。現在は Level 1（LiDAR 反応型）のみ

## 既知の問題
- Pi には rviz2 が未インストール（ros-base のみ）。RViz2 は開発PC側での表示を想定
- `/odom` のノードが未実装のため、オドメトリのテレメトリは現状 null
- LiDAR は `ros-jazzy-rplidar-ros` の導入と `super` の `dialout` グループ所属が必要
- AI HAT+ は `hailo_pci` 4.24.0 と HailoRT 4.24.0 をソース導入済み（Ubuntu 24.04 に `hailo-all` は存在しない。手順は README 参照）。温度は HailoRT C API `hailo_get_chip_temperature()` で取得済み。NPU 使用率と電力はダッシュボードでは扱わない（使用率は `HAILO_MONITOR=1` の推論アプリがある間のみ `hailortcli monitor` で参照可）。電力は未取得（`measure-power` は `UNSUPPORTED_OPCODE`、`query_health_stats()`/`query_performance_stats()` は HAILO8 非対応、`hatctl` は Ubuntu に存在せず Hailo 専用 hwmon も無し、PMIC に HAT 専用レール無し。外付け INA219 等が必要）
- 検出物体の距離は LiDAR の方位角対応による概算で、カメラとLiDARの外部キャリブレーションは未実施（設置が同軸・同方向である前提）
- `perception_node` の推論には HailoRT の Python バインディング（`hailo_platform`）が必要。apt には無いため HailoRT 4.24.0 のソースからビルドして導入する（手順は README 参照）。未導入の場合は LiDAR 判定のみで動作し、`/obstacle_status` の `note` に理由を表示する
- 実機の電源が不足している。ダッシュボード（カメラ＋LiDAR＋Hailo 推論）起動と同時に `hwmon3: Undervoltage detected!` が連発し、2026/09/14 19:22 に shutdown シーケンスなしで電源断した（前回起動だけで 198 回発生、EXT5V は 4.75、5.11V、`get_throttled=0x50000`）。`usb_max_current_enable=0` で 5A PD として認識されておらず、Pi 5 が制限モード（USB 周辺機器 合計 600mA）で動作している。公式 27W USB-C PD 電源への交換と、RPLIDAR の別系統（セルフパワーハブ等）給電が必要
- カメラは Ubuntu 標準の libcamera 0.7.2 だと raspi カーネル 6.8 のエンティティ名不一致で `no cameras available` となる。`~/opt/rpicam` の Raspberry Pi 版 libcamera を使う必要がある（手順は README 参照）
- `vcgencmd get_throttled` が `0x50000` = 過去に低電圧/スロットリングを検出（現在は正常）
- `motor_hat.yaml` の割り付け（M1〜M4 と車輪位置、`reversed`、配線色）は暫定値。実機のモーター配線と照合し、モーター制御ノード実装時に回転方向を確認して修正が必要
- 520 モーターエンコーダーの GPIO 割り付け（`motor_hat.yaml` `encoder` / `gpio_pins.yaml`）は未使用ピンから選んだ暫定値。配線色はエンコーダー基板のコネクタ印字（S2 / S1 / GND / VCC / M− / M+ = 緑 / 橙 / 黄 / 白 / 赤 / 黒）から Motor+ 黒 / Motor− 赤 / VCC 白 / GND 黄 / Encoder A（S1）橙 / Encoder B（S2）緑（Motor+/− は黒-赤間 4Ω・手回し発電で確認。黄を VCC として給電した試験では橙・緑が電源 −0.6V のまま変化せず、逆接続だったと判断。2026/09/24 に M1 を白 VCC 3V3 / 黄 GND で Pi GPIO5/6 に直結し、手回しで A/B 相のパルス（位相差あり）を確認。車輪 1 回転あたり約 2,200 カウント（4 逓倍、手回しのため概算）。前進方向の手回しでカウントは負になる）。公式色表（白 GND / 黄 C1 / 緑 C2 / 青 VCC）は本機のケーブルには適用しない。エンコーダー読み取りノードは未実装
- `gpio_pins.yaml` の配線内容（Motor HAT / BNO055 の I2C・電源・GND、配線色）は HARDWARE_BOM からの暫定値。実配線と照合して修正が必要。TM1637 の配線色は実配線を反映済み（オレンジ・黒・黄・緑）。AI HAT+ の ID EEPROM ピン（27/28）はヘッダー直挿しのため配線色は `PIN` 表記
- WebSocket は `pip install --user --break-system-packages "websockets>=13"` で有効化済み（apt の python3-websockets 10.4 は uvicorn が要求する `ServerProtocol` を持たず、入れると dashboard_node が ImportError で起動しない）。未導入環境では `/api/status` の 250ms ポーリングへ自動フォールバックする
- Motor HAT（Adafruit DC & Stepper Motor HAT）がモーターを駆動しない。2026/09/25 に切り分け、故障と判断して交換を決定。12V は電源ピン 11.94V・HAT 内コンデンサ 12V まで到達し極性も正しいが、緑 LED（電源表示）が点灯しない。Pi から I2C 0x60 に通信でき、駆動中に読み出した PCA9685 の値は M1（ch 8=約 50% / IN1 ch 10 全 ON / IN2 ch 9 全 OFF）・M3（ch 2 / 4 / 3 同様）とも正しく、MODE1=0x01（スリープなし）、ALL_LED 全 OFF なし、PRESCALE=0x03（約 1.5kHz）、`get_throttled=0x0`。それでも 50% で 10 秒駆動中の M1・M3 の出力端子はテスターで 0V（TB6612 #1・#2 とも出力なし）。モーター単体は 12V 直結で回転し、手回しで M1 ピンに ±2V の発電電圧が出るため、モーター・線・端子の接触は正常。2 個の TB6612 が同時に出力せず LED も消灯していることから、共通の電源経路またはドライバーのロジック電源側の故障と推定（故障部品は未特定）。交換品は同型（Adafruit 製品番号 2348、I2C 0x60、M1〜M4 割り付け同じ）で、ソフト・配線表の変更は不要。交換後はまず 12V のみで緑 LED 点灯を確認し、M1 を 30% で短時間駆動して確認する

## テスト結果
- `lcd_display_node`（実機、2026/09/15）: `python3-spidev` / `fonts-ipafont-gothic` を apt 導入、`/dev/spidev0.0` は dialout グループで super から書き込み可。サービス再起動後 `lcd_display_node` が起動し「ST7789 液晶表示を接続しました」、`/display_state` に `rdy ` を publish。`seg_display_node` は起動していないことを確認。2026/09/16 に配線（GND 黒 / VCC 赤 / SCL 橙 / SDA 黄 / RES 緑 / DC 青 / BLK 紫）後、ノード再起動で **正常表示を確認**（SPI モード 3、32MHz、rotation 270 = 反時計回り 90°、横 80px オフセット）。2026/09/17 に更に反時計回り 90° 回転させ rotation 180（縦 80px オフセット）に変更し、実機で **要望通りの向きで正常表示を確認**。配線後はパネル初期化のためノード再起動が必要（起動中に配線しても表示されない）
- `seg_display_node`（実機、2026/09/15、旧表示器）: `python3-libgpiod` を apt 導入後、`gpiochip4 (pinctrl-rp1)` の GPIO23/24 を `seg_display_node` が output で確保（`gpioinfo` で確認）。起動 1 秒で `boot` → `/system_status` 受信後 `rdy` に遷移、`/display_state` を publish。TM1637 配線後に LED の点灯を確認。初回は CLK 線の挿し違いで消灯だった（GPIO24 にはモジュールのプルアップを検出、GPIO23 にはなし → CLK 未接続と判定）。スティック操作時の `HAnd` 表示は未確認
- `imu_node`（実機、2026/09/15）: `i2cdetect -y 1` で 0x29 を検出、`BNO055 接続` ログ後に `/imu/data` を 50.0Hz で受信。加速度の合成値 約9.8m/s²、キャリブレーション gyr=3 まで進行を確認。`/api/status` の `imu` に roll/pitch/yaw・角速度・加速度が入ることを確認（ブラウザ表示は未確認）。`super` を `i2c` グループへ追加が必要（未所属だと Permission denied）
- 取り付け向き: 静止時に加速度 x≈6.9 / y≈4.0 / z≈-5.8 と重力が z 軸に乗っておらず、センサーの搭載向きが `imu_link`（機体と同一向き）と一致していない。向き確定後に軸の入れ替え（またはURDF の `imu_joint` の rpy）で補正が必要
- `colcon build --symlink-install`: 2パッケージ成功
- `xacro ai_car.xacro`: URDF 生成成功（10リンク）
- `ros2 launch ai_car_web dashboard.launch.py`: 起動成功
  - `GET /` → 200
  - `GET /api/status` → JSON 応答
  - `POST /api/cmd_vel {linear_x:1.0, angular_z:0.5}` → `{linear_x:0.3, angular_z:0.5}`（最大速度でスケール）
- `system_monitor_node`: `/system_status` の JSON 取得成功（CPU 48.3℃ / 合計 2.17W / EXT5V 4.84V / Hailo-8 PCIe 検出）
- HailoRT 導入後の `/api/status`: `driver_ready: true` / `hailo_pci 4.24.0` / FW 4.24.0 / HAILO8 / PCIe 8.0 GT/s x1 を取得
- AI HAT+ 温度: `/api/status` の `system.hailo.temperature_c` で 49.6℃ を取得（ts0/ts1 平均、取得時間 約30ms）
- `GET /api/status` に `system` フィールドが含まれることを確認
- ブラウザ表示確認: CPU / メモリ / 電源 / AI HAT+ の各カードが実値で更新されることを確認（ポーリングフォールバック経由）
  - `/cmd_vel` トピック publish と指令タイムアウト停止のログを確認
- カメラ（IMX708）: Raspberry Pi 版 libcamera v0.7.2+rpt20260817 / libpisp v1.7.0 を `~/opt/rpicam` にビルドし、`cam -l` でカメラ認識を確認
- `ros2 launch ai_car_web dashboard.launch.py`（カメラ含む）: `/camera/image_raw/compressed` 30Hz、`/api/status` の `camera.available: true`、`GET /api/camera/snapshot` → 200（約53KB JPEG）を確認
- LiDAR（RPLIDAR, CP2102 USB）: `rplidar_composition` 起動で `/scan` を 約8Hz で受信。ダッシュボードの点群マップに最大720点（有効点は実測約477点）が描画されることをブラウザで確認
- 障害物判定: `/obstacle_status` で `level: stop`（前方 0.177m）を確認。Hailo-8 推論は約 8ms、YOLOv8n で物体検出（例: bed 0.61 / sink 0.50）を確認。温度閾値を一時的に下げて warn（推論 40%）→ critical（推論停止、LiDAR 判定は継続）→ 復帰を確認
- F710 手動操作: 実機で `joy_teleop_node` が `Logitech Gamepad F710 (/dev/input/js0)` を検出し `/joy_cmd` 10Hz を確認。`/joy_cmd {x:0.5, y:-0.5, z:0.5}` を publish → `/cmd_vel {x:0.075, y:-0.15, z:0.5}`（最大速度 0.3/1.0 と前方障害物による減速 0.5 が適用）を確認。入力停止 → 0.7 秒後に「指令タイムアウトのため停止しました」を確認。`/api/status` の `joy.connected / active` を確認。スティックの実操作による前後・左右の向きは未確認（ユーザーによる実機確認が必要）
- Motor HAT 接続図: `load_motor_hat('config/motor_hat.yaml')` で 4 端子の割り付けと警告なし、YAML 不在時は `error` を返すことを確認。開発 PC 上で `/api/motor_hat` を模擬した静的サーバーにより、ブラウザで接続図（4 輪・配線・端子台）と一覧表の表示を確認。実機（AI-CAR）で `GET /api/motor_hat` が 200 で割り付けを返すことと、I2C 0x60 に Motor HAT を検出することを確認。エンコーダー割り付けは `load_motor_hat` で警告なし・BCM 解決を確認し、`build_pinout` で信号ピンの競合なし（使用 25/40）を確認。開発 PC のブラウザでエンコーダーピン付きの接続図・一覧表を確認（実機は未反映）。`flake8 --max-line-length 100` エラー無し
- GPIO ヘッダー: `build_pinout('config/gpio_pins.yaml')` で使用中 9 ピン（1,2,3,4,5,6,9,27,28）、YAML 不在時は `error` を返すことを確認。実機で `GET /api/gpio` → `used_count: 9`、ブラウザでヘッダー図（上下段ラベルの重なり無し）と 40 行の一覧表の表示を確認。`flake8 --max-line-length 100` エラー無し
- `ros2 launch ai_car_description view_robot.launch.py`: 起動成功（`/robot_description`・`/joint_states`・`/tf` 発行を確認）

## カメラ仕様（実測）
- 3D プリント部品（PR #80、未印刷）: Pi 5 は台の左に寄せ（基板の中心 X 47 mm）、カバーの左の穴から電源ボタンを押せる。右の USB / LAN 側はカバーの壁まで約 61 mm あき、ストレートの USB プラグも入る。印刷後に、ボタンの位置が穴に合うかとプラグが当たらないかを確かめる
- 2026/10/09 から前方カメラは Camera Module 3 Wide（IMX708、`camera_ros`、`camera_type:=picam` が既定）。横の画角 102°（公称）、レンズの先は LiDAR の回転中心の真ん前 63 mm。960×540・30.1 fps を実測。2 眼カメラは外してあり、2 眼の距離（`stereo_depth_node`）と低い物の判定は動かない。かわりに 1 眼の奥行きの AI（SC-Depth v3、`perception_node` の `mono_depth_hef`）で低い物を見つける（表示だけ、`mono_depth_guard: false`）
- 2026/10/01〜10/08 の前方カメラは USB の 2 眼カメラ（ELP 3D USB Camera、`stereo_camera_node`、`camera_type:=stereo`）。MJPG を 1/2 の大きさで展開して（`decode_reduce: 2`）、左目を 640×360・15fps で配信（キャリブレーションの撮影だけ元の 1280×720）。MJPG のモード: 3840×1080 / 2560×720 / 1600×600 / 1280×480 / 640×240（各 5〜60fps）。USB 2.0（480M）で認識。CPU 約 52%（15fps）。電源は取り込み中 4.94〜5.0V・1.32A、`get_throttled=0x0`。画角（仮 120°）と取り付け位置は未実測。2 眼で距離を測る準備として、キャリブレーションの撮影（カメラカードの「撮影」）と計算（`ros2 run ai_car_web stereo_calibrate`）の道具を用意した（手順は `docs/calib/README.md`）。2026/10 に 28 組を撮って計算した（誤差 0.33 px、平行化後の上下のずれ 0.19 px、レンズの間隔 59.8 mm、画角 横 115° / 縦 82°。Pi の `~/AI-CAR_ws/calib/stereo/stereo_calib.yaml`）。画面の下 3 分の 1 には模様が写っていないので、車のすぐ前の床の距離は少しずれるかもしれない。`stereo_depth_node` がこの値で左右を平行にそろえ、SGBM（片目 640×360、視差 0〜96 px で約 0.14 m から。64 px のときは約 0.21 m より近い物をまちがえた）で距離を出す（表示だけ）。撮った画像で、市松模様までの距離は 0.39 / 0.29 / 1.13 m（PnP で 0.39 / 0.33 / 1.17 m）、床の高さの中央値は 0.00〜0.02 m（`camera_height_m` 0.112・`camera_pitch_deg` 0 で合っている）。AI HAT+ の StereoNet（Hailo Model Zoo v2.19.0、入力 1232×368 の左右）は、この Pi で 1 秒 4.8 枚（公表値 10.7 枚）、YOLOv8m と交代で動かすと両方 1 秒 4.1 回（YOLOv8m だけなら 28.7 回）だったので使わず、距離は CPU の SGBM で出す予定（2026/10 実測）。下の Camera Module 3 の値は `camera_type:=picam` のとき
- 解像度: 960x540 / JPEG 品質 80（IMX708 / Camera Module v3、`config/dashboard.yaml` の `width`/`height`/`jpeg_quality`）。1 枚 約42〜53KB
- ROS 配信レート: 約 30Hz（`/camera/image_raw/compressed`、`FrameDurationLimits` [33333, 33333]、実測 30.04Hz）
- ダッシュボード MJPEG: 30fps（`camera_stream_rate`）
- AI HAT+ 推論: YOLOv8m、640x640 にレターボックスして 15Hz 設定（推論タイマー 0.02秒）。推論 約32.6ms、dashboard CPU 28〜33%、CPU 53.8〜54.3℃、Hailo 49.6〜50.7℃、サーマル状態 normal
- 電源: 12V 系 → DROK 降圧コンバータ 5.2V/5A → USB-C。`/boot/firmware/config.txt` に `usb_max_current_enable=1`（USB-A からなので PD のやりとりはなく、ラズパイが認識する電源の上限は 3 A。ダッシュボードの「電源の電流上限」は `power.supply` = device tree の `chosen/power/max_current`）。実測 入力電圧 4.96〜5.02V、`get_throttled=0x0`（低電圧履歴なし）。以前のモバイルバッテリー（CIO SMARTCOBY Pro SLIM 35W、5V 時 3A 上限）では 4.77〜4.90V・低電圧フラグが発生していた
- 低負荷設定（カメラ 15fps・推論 5Hz・テレメトリ 5Hz・LiDAR 360 点）時の参考値: dashboard CPU 18.4〜21.1%、camera_node 約18.1%、perception_node 約16.5%、dashboard_node 約16.8%

## 次回作業
- Motor HAT を同型品に交換し、12V 投入で緑 LED 点灯 → M1〜M4 を 30% で短時間駆動して出力と回転を確認する
- 実機で自動モードの走行挙動（旋回方向・速度・距離しきい値）を確認し `autonomy_node` のパラメータを調整する（モーター配線後）
- モーター制御ノード（`/cmd_vel` 購読 → Motor HAT 駆動）を実装する。`motor_hat.yaml` の割り付け（`channel` / `wheel` / `reversed`）を参照してメカナム逆運動学の出力を各端子へ振り分ける
- 実配線（M1〜M4とエンコーダージャンパー線）に合わせて `motor_hat.yaml` / `gpio_pins.yaml` を修正する
- エンコーダー読み取りノード（libgpiod で A/B 相をカウントし `/wheel_ticks` 等を publish）を実装し、カウント方向を確認する

## 変更ファイル
- `/home/super/AI-CAR_ws/src/ai_car_web/ai_car_web/drive_mode_node.py` - 新規作成（運転モード管理）
- `/home/super/AI-CAR_ws/src/ai_car_web/ai_car_web/autonomy_node.py` - 新規作成（Level 1 自律走行）
- `/home/super/AI-CAR_ws/src/ai_car_web/ai_car_web/lcd_display_node.py` - 新規作成（ZJY-IPS130-V2.0 / ST7789 液晶表示）
- `/home/super/AI-CAR_ws/src/ai_car_web/{setup.py, config/dashboard.yaml, config/gpio_pins.yaml, launch/dashboard.launch.py}`、`HARDWARE_BOM.md`、`README.md` - 液晶表示器への置き換えで更新
- `/home/super/AI-CAR_ws/src/ai_car_web/{ai_car_web/dashboard_node.py, ai_car_web/joy_teleop_node.py, ai_car_web/seg_display_node.py, config/dashboard.yaml, launch/dashboard.launch.py, setup.py, static/index.html}` - 運転モード切替・自律走行対応で更新
- `/home/super/AI-CAR_ws/src/ai_car_description/` - 新規作成（package.xml, CMakeLists.txt, urdf/, launch/, rviz/, config/, meshes/）
- `/home/super/AI-CAR_ws/src/ai_car_web/` - 新規作成（package.xml, setup.py, setup.cfg, ai_car_web/dashboard_node.py, launch/, config/, static/）
- `/home/super/AI-CAR_ws/src/ai_car_web/ai_car_web/system_monitor_node.py` - 新規作成
- `/home/super/AI-CAR_ws/src/ai_car_web/{setup.py, package.xml, config/dashboard.yaml, launch/dashboard.launch.py, static/index.html, ai_car_web/dashboard_node.py}` - システム監視対応で更新
- `/home/super/AI-CAR_ws/systemd/{ai-car-dashboard.service, install_service.sh}` - 新規作成（自動起動）
- `/home/super/AI-CAR_ws/src/ai_car_web/ai_car_web/gpio_pinout.py`、`config/gpio_pins.yaml` - 新規作成（GPIO ピン配置）
- `/home/super/AI-CAR_ws/src/ai_car_web/{ai_car_web/dashboard_node.py, config/dashboard.yaml, package.xml, static/index.html}` - GPIO カード対応で更新
- `/home/super/AI-CAR_ws/src/ai_car_web/ai_car_web/joy_teleop_node.py` - 新規作成（F710 手動操作）
- `/home/super/AI-CAR_ws/src/ai_car_web/{ai_car_web/dashboard_node.py, setup.py, launch/dashboard.launch.py, config/dashboard.yaml, static/index.html}` - F710 対応で更新
- `/home/super/AI-CAR_ws/src/ai_car_web/ai_car_web/seg_display_node.py` - 新規作成（TM1637 7セグ表示）
- `/home/super/AI-CAR_ws/src/ai_car_web/{setup.py, package.xml, config/dashboard.yaml, launch/dashboard.launch.py, config/gpio_pins.yaml}` - TM1637 7セグ表示対応で更新
- `/home/super/AI-CAR_ws/src/ai_car_web/ai_car_web/imu_node.py` - 新規作成（GY-BNO055 I2C IMU）
- `/home/super/AI-CAR_ws/src/ai_car_web/{setup.py, config/dashboard.yaml, launch/dashboard.launch.py, config/gpio_pins.yaml, static/index.html}` - IMUノード対応で更新
- `/home/super/AI-CAR_ws/src/ai_car_web/ai_car_web/motor_hat.py`、`config/motor_hat.yaml` - 新規作成（Motor HAT M1〜M4 割り付け）
- `/home/super/AI-CAR_ws/src/ai_car_web/{ai_car_web/dashboard_node.py, config/dashboard.yaml, static/index.html}` - Motor HAT 接続図カード対応で更新
- `/home/super/AI-CAR_ws/src/ai_car_web/{ai_car_web/architecture.py, ai_car_web/dashboard_node.py, config/architecture.yaml, config/dashboard.yaml, static/index.html}` - プロジェクト説明モーダルと `/api/architecture`
- `/home/super/AI-CAR_ws/src/ai_car_web/{ai_car_web/motor_hat.py, config/motor_hat.yaml, config/gpio_pins.yaml, static/index.html}`、`HARDWARE_BOM.md` - 520 モーターエンコーダーの Pi GPIO 割り付けを追加
- `/home/super/AI-CAR_ws/PROJECT_STATUS.md` - 本ファイル
- `/home/super/AI-CAR_ws/CHANGELOG.md` - 更新

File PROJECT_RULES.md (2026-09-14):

# PROJECT_RULES.md

## プロジェクト概要
- Raspberry Pi 5上でROS2 Jazzyを使用する。
- LiDAR、カメラ、Nav2、FastAPIを使用する。
- AI-CAR ロボット開発プロジェクト。

## 基本方針
- 既存の動作確認済みコードを削除しない。
- 既存仕様を変更する前に、影響範囲と理由を説明する。
- 新機能は可能な限り新規ノードとして追加する。
- 1ノード1責務を基本とする。
- 回答とドキュメントは日本語とする。

## 作業開始時
- PROJECT_STATUS.mdを読む。
- 現状を要約してから実装計画を提示する。

## 作業終了時
- 実施したテストと結果を報告する。
- PROJECT_STATUS.mdを更新する。
- 変更ファイル一覧と残課題を報告する。

## 禁止事項
- ユーザー承認なしにTopic名、Interface、Launch構成を変更しない。
- build/、install/、log/を解析対象にしない。
- 未テスト機能を「完了」と記録しない。
-解説や挨拶文などのテキスト出力は一切不要です。

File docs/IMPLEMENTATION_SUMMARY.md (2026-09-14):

# AI-CAR ロボット開発プロジェクト - 実装概要

## プロジェクト概要
- **プロジェクト名**: AI-CAR ロボット開発プロジェクト
- **実行環境**: Raspberry Pi 5
- **ROSバージョン**: ROS2 Jazzy（ros-base）
- **主な技術スタック**: LiDAR、カメラ、IMU、Nav2（未導入）、FastAPI

## 実装済み機能
- `ai_car_description`
  - URDF/Xacro（`urdf/ai_car.xacro`）: base_footprint、base_link、メカナム4輪、laser、camera_link、camera_optical_frame、imu_link
  - Launch（`launch/view_robot.launch.py`）: robot_state_publisher、joint_state_publisher、`use_gui` / `use_rviz` / `use_sim_time`
  - RViz2設定（`rviz/ai_car.rviz`）: RobotModel / TF / LaserScan
- `ai_car_web`
  - `dashboard_node`: FastAPI（別スレッド）+ rclpy
  - Publish `/cmd_vel`、Subscribe `/scan`・`/imu/data`・`/odom`
  - REST `/api/status`・`/api/cmd_vel`・`/api/stop`、WebSocket `/ws`
  - 手動操作UI（メカナム前後・平行移動・旋回、出力ゲイン）とテレメトリ表示
  - 無指令タイムアウト（既定0.7秒）による自動停止

## 未実装機能
- LiDARノード（RPLIDAR A1M8 ドライバ）
- カメラノード
- IMUノード（BNO055）
- モーター制御ノード（Adafruit Motor HAT、メカナム逆運動学）
- オドメトリ発行
- SLAM、Nav2自律走行

## ハードウェア構成
- Raspberry Pi 5 (8GB RAM)
- Raspberry Pi AI HAT+ (26TOPS NPU)
- Adafruit DC & Stepper Motor HAT
- Raspberry Pi カメラモジュール v3
- LiDAR（RPLIDAR A1M8）
- 9軸 IMU（GY-BNO055）
- メカナムホイール駆動系
- バッテリー（5V/12V系統）

## 次回作業計画
1. モーター制御ノードを実装し `/cmd_vel` で実走行させる
2. LiDAR / カメラ / IMU ノードを実装する
3. オドメトリと TF を整備する
4. SLAM と Nav2 を導入する
5. ダッシュボードにカメラ映像と地図表示を追加する

## プロジェクト管理
- プロジェクトルール: PROJECT_RULES.md
- 実装状況管理: PROJECT_STATUS.md
- 変更履歴: CHANGELOG.md

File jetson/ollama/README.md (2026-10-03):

# Ollama（会話の AI）の設定

Jetson の声のやりとりで使う会話の AI（`qwen2.5:3b`）を、いつもメモリに読み込んだままにします。
Ollama は、ふつうは 5 分使わないとモデルをメモリから外すので、その次の 1 回目の返事が数秒遅くなります。

- `voice.conf`: `ollama.service` の追加設定。同時に 1 人だけ答える（`NUM_PARALLEL=1`）、
  モデルは 1 つだけ（`MAX_LOADED_MODELS=1`）、メモリを減らす（`FLASH_ATTENTION`・`KV_CACHE_TYPE=q8_0`）、
  外さない（`KEEP_ALIVE=-1`）
- `ollama-preload.service`: 電源を入れたとき、Ollama が起動したら `qwen2.5:3b` を読み込む

メモリ（8 GB）のうち、約 2.5 GB を GPU 側でずっと使います。NanoOWL を止めた状態で、空きは約 1.2 GB です。

## 入れ方（Jetson）
```bash
sudo install -m 644 voice.conf /etc/systemd/system/ollama.service.d/voice.conf
sudo install -m 644 ollama-preload.service /etc/systemd/system/
sudo systemctl daemon-reload
sudo systemctl restart ollama.service
sudo systemctl enable --now ollama-preload.service
ollama ps   # UNTIL が Forever になる
```

一時的にメモリを空けたいときは `ollama stop qwen2.5:3b`（次に話しかけると、また読み込みます）。

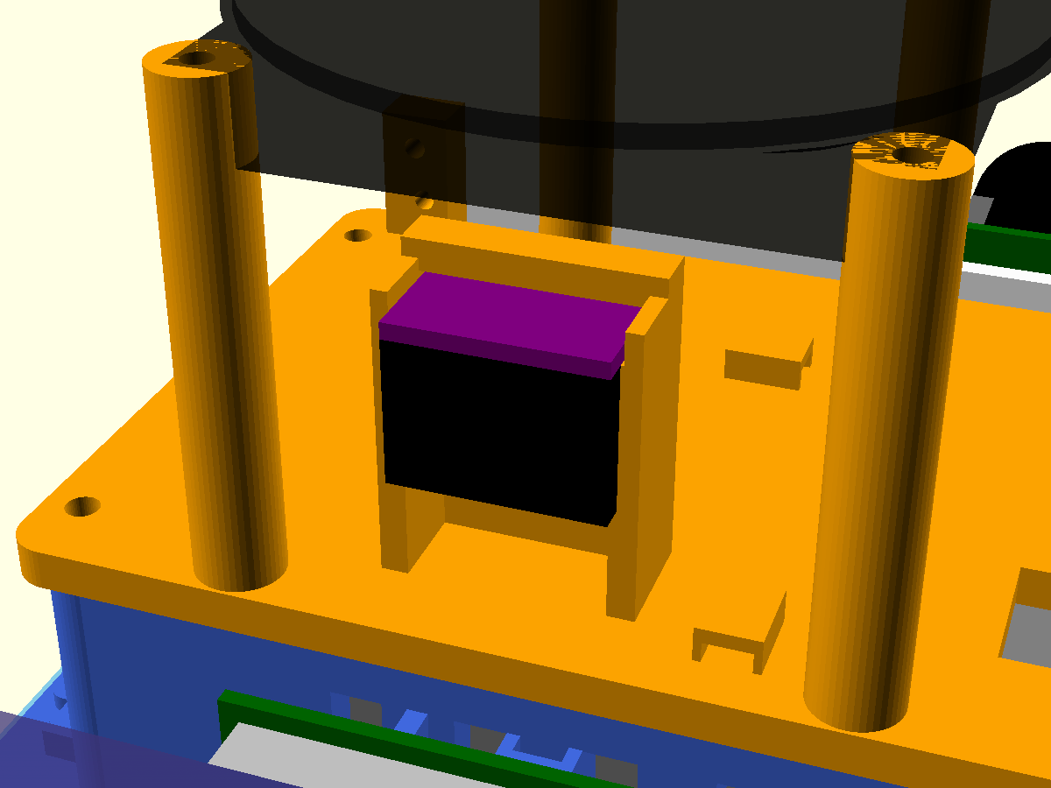
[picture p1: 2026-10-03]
hardware/3d/battery_lidar_mount/sensors.png

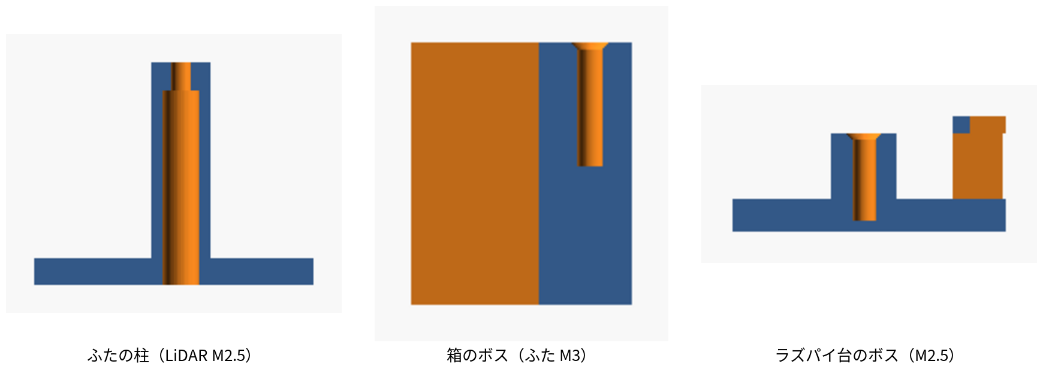
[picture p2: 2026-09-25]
hardware/3d/battery_lidar_mount/screw_holes.png

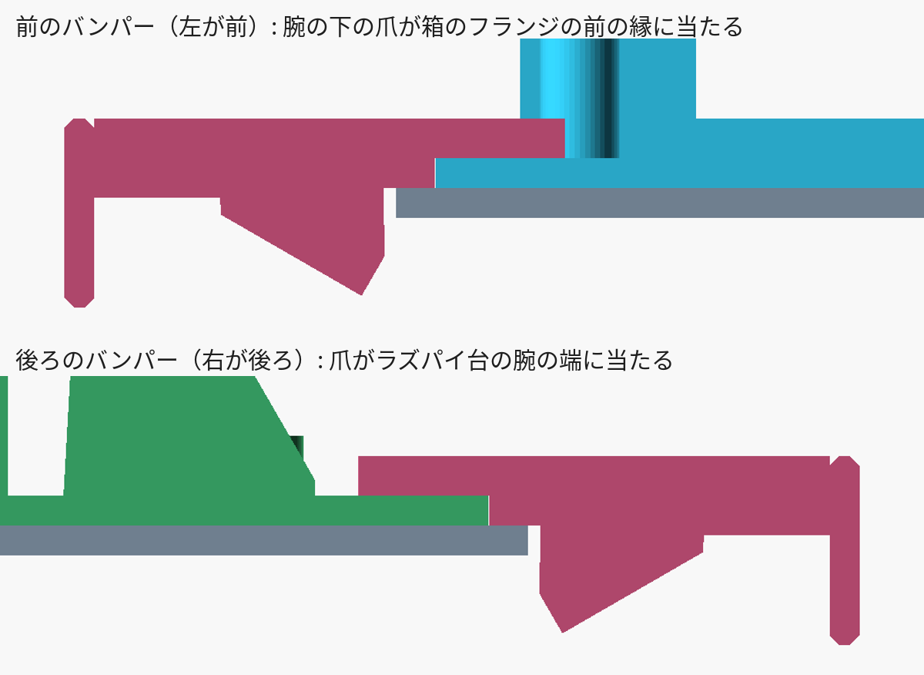
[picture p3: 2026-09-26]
hardware/3d/battery_lidar_mount/bumper_hook.png

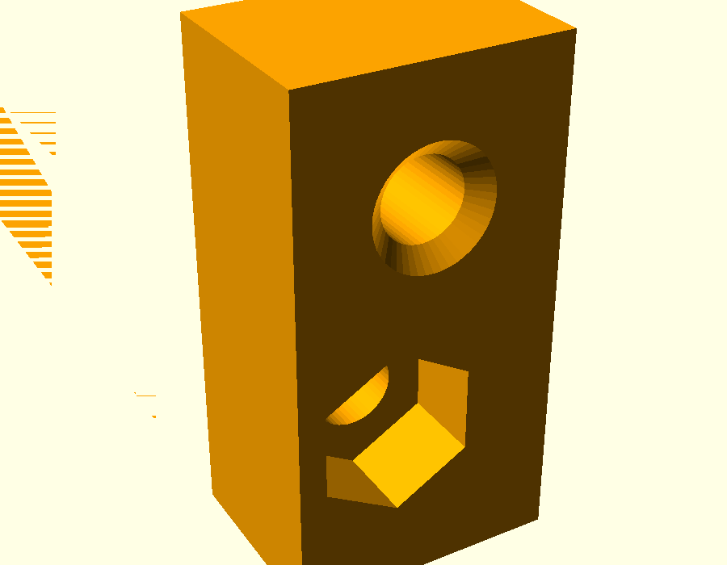
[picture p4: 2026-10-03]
hardware/3d/battery_lidar_mount/cam_post_nut.png

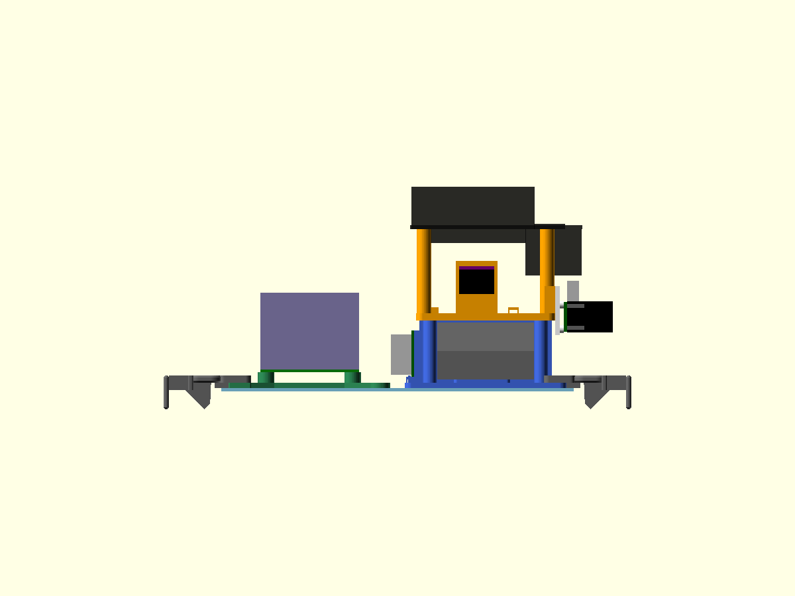
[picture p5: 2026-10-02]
hardware/3d/battery_lidar_mount/side.png

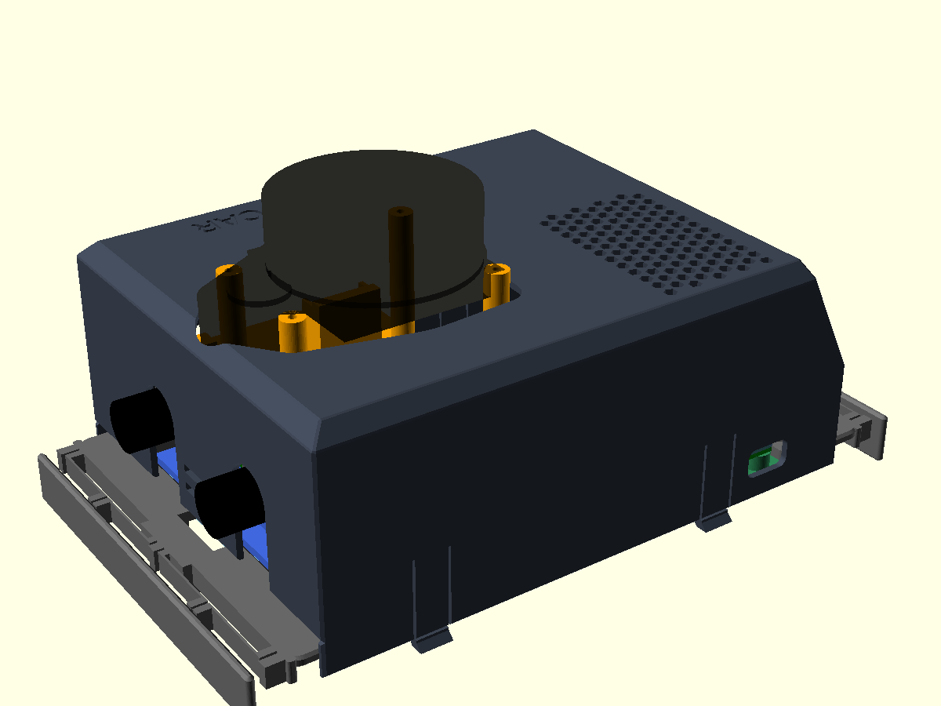
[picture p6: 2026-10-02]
hardware/3d/battery_lidar_mount/cover_rear.png

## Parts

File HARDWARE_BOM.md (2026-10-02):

# HARDWARE_BOM.md — AI-CAR 部品構成表

## 概要
AI-CAR（自律走行ロボットカー）のハードウェア構成を記録する。

---

## 部品リスト

| No | 部品名 | 仕様・備考 | 接続方法 |
|----|---|---|---|
| 1 | **Raspberry Pi 5** | 8GB RAM（メインボード） | — |
| 2 | **Raspberry Pi AI HAT+** | 26TOPS NPU（推論アクセラレーション） | Pi 5 GPIO ヘッダー |
| 3 | **Adafruit DC & Stepper Motor HAT** | モーター駆動制御（4ch） | Pi 5 GPIO ヘッダー（I²C） |
| 4 | **Raspberry Pi カメラモジュール v3** | 960×540・30fps | CSI バス |
| 5 | **LiDAR（RPLIDAR A1M8）** | 2D レーザースキャナ（最大距離8m） | USB シリアル |
| 6 | **9軸 IMU（GY-BNO055）** | 加速度・ジャイロ・地磁気融合 | I²C |
| 8 | **Logicool G ゲームパッド** | 手動操作ジョイスティック | USB Bluetooth |
| 9 | **メカナムホイール駆動系** | オムニディレクショナル移動（4輪）。OSOYOO 520 エンコーダー付きモーター ×4（2024005900、Ø37 × 72 mm、軸 Ø4 D カット、56:1）、メカナムホイール Ø80.59 × 幅 39.1 mm（六角穴 6.5 mm）、37 mm モーター台 ×4（天板の下、穴 24 × 30 mm） | モーター HAT 経由（エンコーダーは Pi GPIO 直結） |
| 9a | **エンコーダー用ジャンパー線** ×2 | 25cm、2.54mm ピッチ、メス-メス 6ピン to 6ピン。OSOYOO 520 モーターエンコーダー↔Pi 接続専用。型番 2024006000 | モーター 6ピン → HAT M端子（M+/M−）と Pi ヘッダー（VCC/GND/A/B） |
| 10 | **バッテリー（CIO SMARTCOBY Pro SLIM 35W）** ×2 | 10000mAh、USB-C PD（12V 出力）。3D プリントの箱に 2 個重ねて収納 | USB-C PD 12V → DROK 降圧コンバーター / Motor HAT |
| 10a | **DROK 降圧コンバーター**（B09JKHD3SH） | DC 9〜36V → 5.2V / 5A、USB-A 出力。基板 63×27 mm | 12V 入力（DC ジャック / 端子）→ USB-A → Pi 5 USB-C |
| 10b | **落下防止センサー（Dovhmoh VL53L1X）** ×2 | ToF 測距、3〜5V。前後バンパーに真下から進行方向へ 45° 傾けて取付。I²C 初期アドレス 0x29（BNO055 と重なるため、`cliff_node` が XSHUT を 1 台ずつ上げて前 0x30 / 後 0x31 に変更）。未配線・配線色は未定（予定: 前 VIN pin 1 / GND 14 / XSHUT 11、後 VIN pin 17 / GND 25 / XSHUT 13、SDA / SCL は pin 3 / 5 を共有） | I²C バス 1 ＋ XSHUT GPIO17 / GPIO27 |
| 11 | **配線ケーブル一式** | 接続用 | — |
| 12 | **シャーシ（ロボット車体）** | 機械構造 | — |

---

## システム構成図（論理）

```
┌─────────────────────────────────────────────┐
│              Raspberry Pi 5 (8GB)            │
│                                             │
│  ┌──────────┐   ┌──────────┐               │
│  │ ROS2     │   │ FastAPI  │               │
│  │ Jazzy    │   │ Server   │               │
│  │ Nav2     │   │          │               │
│  │ SLAM     │   └──────────┘               │
│  │ Toolbox  │                               │
│  └──────────┘                               │
│                                             │
│  AI HAT+ (NPU 26TOPS) ← 推論オフロード      │
└─────┬──────────┬──────────┬─────────────────┘
      │          │          │
   CSIバス     I²C        USB シリアル
      │          │          │
  カメラv3    IMU       RPLIDAR A1M8
            BNO055
```

---

## 電源構成

| 系統 | 供給元 | 供給先 |
|---|---|---|
| 5V | バッテリー（5V系統） | Raspberry Pi 5、センサー類 |
| 12V | バッテリー（12V系統） | Adafruit Motor HAT → メカナムホイール駆動系 |

> **注意**: 電源はバッテリーから 5V と 12V の2系統で供給される。12V はモータードライバー専用であり、Raspberry Pi 側には接続しない。

---

## Motor HAT モーター端子の割り付け（`src/ai_car_web/config/motor_hat.yaml`）

車輪の呼び方は進行方向基準で「**M1 前左**」のように端子名＋位置で統一する。モーター線は **黒 Motor+ / 赤 Motor−**（6 本の内訳は次節）。

| 端子 | 車輪 | Motor+ / Motor− | 回転 | TB6612 | PCA9685 ch (PWM / IN1 / IN2) |
|---|---|---|---|---|---|
| M1 | 前左（front_left） | 黒 / 赤 | 正転 | #1 A | 8 / 10 / 9 |
| M2 | 前右（front_right） | 黒 / 赤 | 反転 | #1 B | 13 / 11 / 12 |
| M3 | 後左（rear_left） | 黒 / 赤 | 正転 | #2 A | 2 / 4 / 3 |
| M4 | 後右（rear_right） | 黒 / 赤 | 反転 | #2 B | 7 / 5 / 6 |

> 暫定値。実配線と照合し、モーター制御ノードで回転方向を確認して `reversed` を修正する。

### モーター 1 台 6 本の接続先（`motor_hat.yaml` の `encoder` / `gpio_pins.yaml`）

各モーターの 6 ピン配線。配線色はエンコーダー基板のコネクタ横の印字 **S2 / S1 / GND / VCC / M− / M+**（線は順に 緑 / 橙 / 黄 / 白 / 赤 / 黒）で確認した（Motor+/− はテスターで黒-赤間 4Ω・手回しで発電も確認）。公式の色表（白 GND / 黄 C1 / 緑 C2 / 青 VCC）は本機のケーブルには適用せず、VCC / GND を逆に挿すとエンコーダーを壊す恐れがあるため、基板印字とコネクタのピン番号で確認する:

| 配線色 | ピン名称 | 役割 | 接続先 |
|---|---|---|---|
| 黒 | Motor+ (M+) | モーター駆動電源（正極 DC 12V） | Motor HAT M端子 + |
| 赤 | Motor− (M−) | モーター駆動電源（負極） | Motor HAT M端子 − |
| 白 | VCC | エンコーダー用電源（DC 3.3〜5V） | Motor HAT (3V3 power) |
| 黄 | GND | エンコーダー用グランド | Motor HAT (Ground) |
| 橙 | Encoder A (S1) | A 相パルス出力 | Pi GPIO |
| 緑 | Encoder B (S2) | B 相パルス出力 | Pi GPIO |

> **注意**: 赤（Motor−）と黒（Motor+）はモーター端子の 2 本で、一般的な「赤 = 電源 + / 黒 = GND」ではない。どちらも Motor HAT の M 端子以外（Pi や電池の GND など）にはつながない。入れ替えても回転方向が逆になるだけで故障しない。

Adafruit Motor HAT にエンコーダー入力はないため、Motor+/Motor− は HAT の M 端子へ、VCC / GND は Motor HAT (3V3 power) / Motor HAT (Ground) へ、Encoder A / B は Pi GPIO へエンコーダー用ジャンパー線で接続する（OSOYOO の資料では PWM HAT 経由だが本機は Pi 直結）。

| モーター | Motor+ 黒 | Motor− 赤 | VCC 白 | GND 黄 | Encoder A 橙 | Encoder B 緑 |
|---|---|---|---|---|---|---|
| M1 前左 | HAT M1 + | HAT M1 − | Motor HAT (3V3 power) | Motor HAT (Ground) | Pi pin 29 (GPIO5) | Pi pin 31 (GPIO6) |
| M2 前右 | HAT M2 + | HAT M2 − | Motor HAT (3V3 power) | Motor HAT (Ground) | Pi pin 33 (GPIO13) | Pi pin 35 (GPIO19) |
| M3 後左 | HAT M3 + | HAT M3 − | Motor HAT (3V3 power) | Motor HAT (Ground) | Pi pin 37 (GPIO26) | Pi pin 32 (GPIO12) |
| M4 後右 | HAT M4 + | HAT M4 − | Motor HAT (3V3 power) | Motor HAT (Ground) | Pi pin 36 (GPIO16) | Pi pin 38 (GPIO20) |

- VCC / GND は Motor HAT (3V3 power) / Motor HAT (Ground) を使う（`motor_hat.yaml` の `power_board: Motor HAT`）。VCC は **3V3**（4 台共通）。仕様上は 5V も可だが Encoder A/B 出力が GPIO 直結のため 5V は使わない
- I2C（pin 3/5）は避けている
- GPIO ヘッダー表（ダッシュボード）では VCC / GND のピンは Motor HAT 側に挿すため空き表示、Encoder A / B のみ使用中

> Pi 側のピン割り付けは暫定値。M1 は白 Motor HAT (3V3 power) / 黄 Motor HAT (Ground) / 橙 GPIO5 / 緑 GPIO6 で A/B 相パルスを確認済み（車輪 1 回転あたり約 2,200 カウント、4 逓倍の概算。前進方向の手回しでカウントは負）。A/B の逆相（カウント方向）はエンコーダー読み取りノードで符号を合わせる。

---

## メモ
- カメラ解像度は 960×540 / 30fps・JPEG 品質80 に設定（CPU 負荷とダッシュボード表示の滑らかさのバランス）
- AI HAT+ は NPU 推論用（ROS2 ノードと連携）
- GY-BNO055 は ROS2 の `imu` トピックを公開

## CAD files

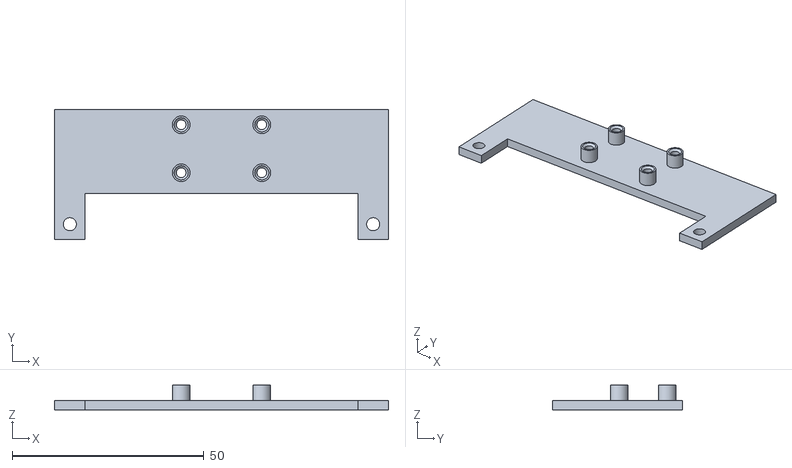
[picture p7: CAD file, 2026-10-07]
hardware/3d/battery_lidar_mount/cam_mount.stl
87.0 x 33.9 x 6.50

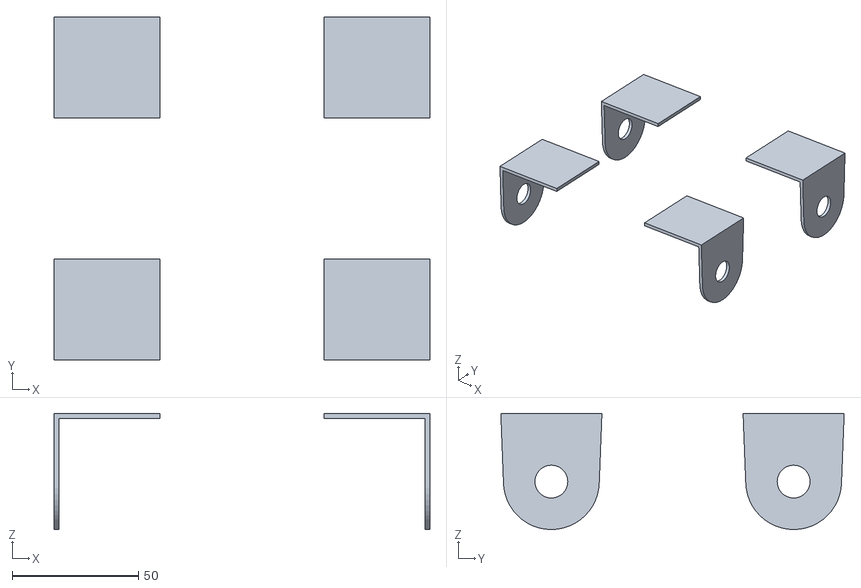
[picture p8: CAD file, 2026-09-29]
hardware/3d/drivetrain/holders.stl
149.0 x 136.0 x 46.0

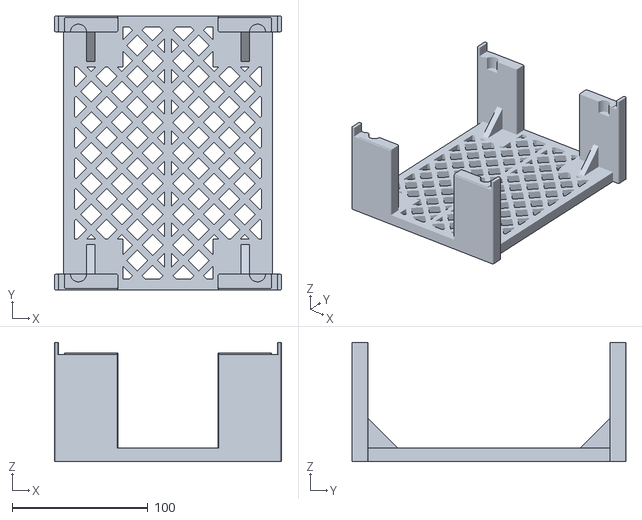
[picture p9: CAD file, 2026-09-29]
hardware/3d/test_stand/test_stand.stl
167.4 x 202.0 x 88.0

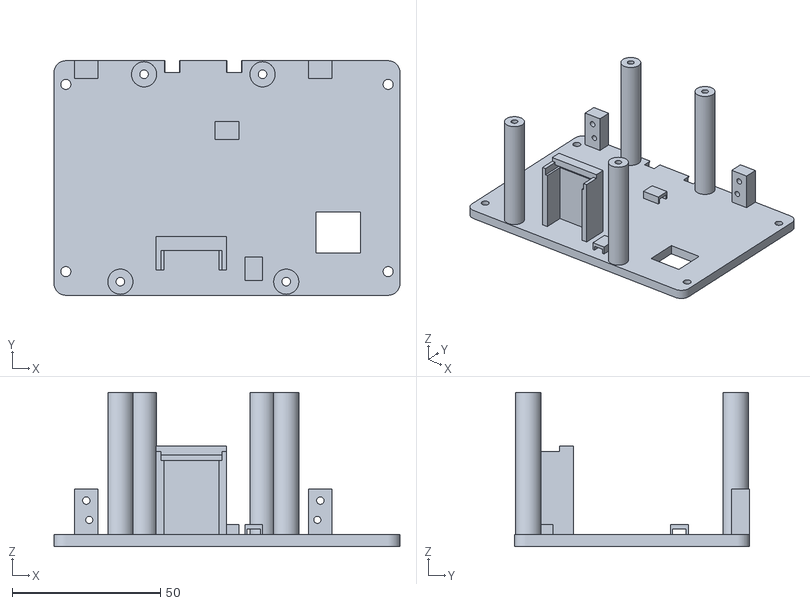
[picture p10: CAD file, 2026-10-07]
hardware/3d/battery_lidar_mount/lid.stl
116.8 x 79.2 x 52.0

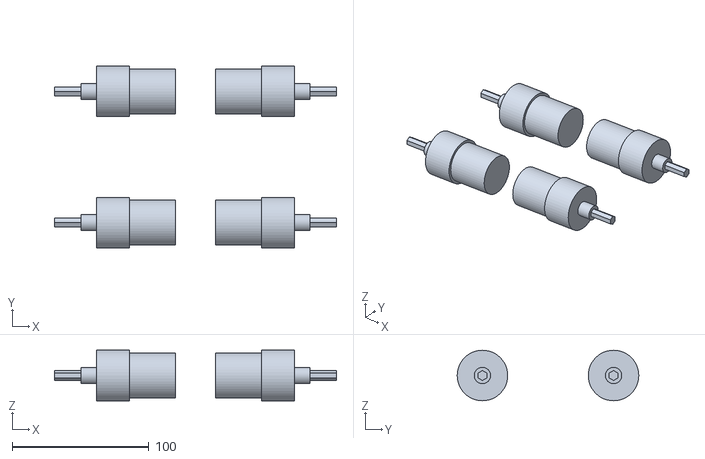
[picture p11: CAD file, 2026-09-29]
hardware/3d/drivetrain/motors.stl
206.5 x 133.0 x 37.0

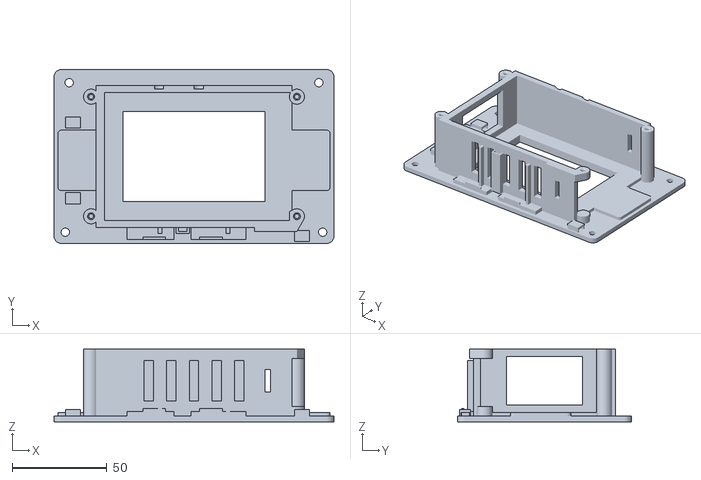
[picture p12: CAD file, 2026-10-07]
hardware/3d/battery_lidar_mount/box.stl
148.0 x 92.0 x 38.4

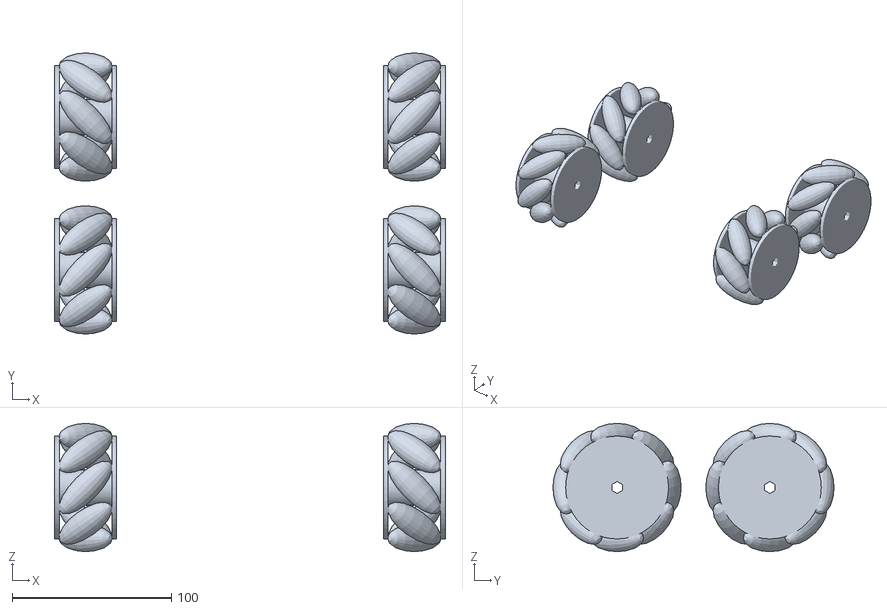
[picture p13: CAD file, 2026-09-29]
hardware/3d/drivetrain/wheels.stl
245.6 x 176.6 x 80.6

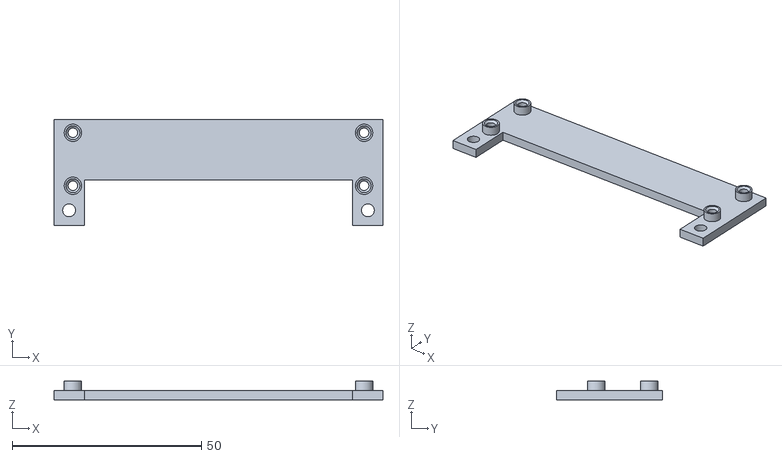
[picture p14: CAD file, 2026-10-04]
hardware/3d/battery_lidar_mount/cam_mount_stereo.stl
87.0 x 28.0 x 5.00

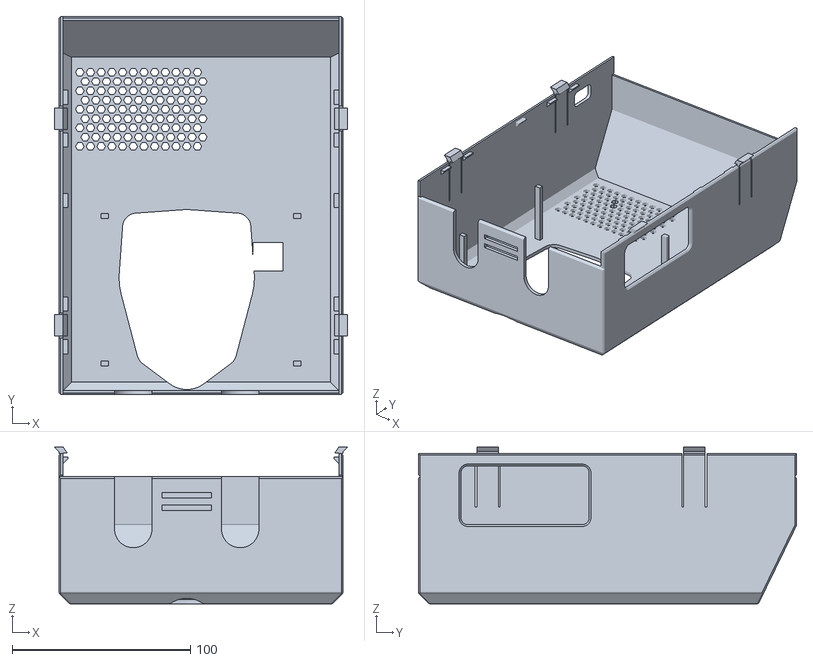
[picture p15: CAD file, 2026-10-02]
hardware/3d/battery_lidar_mount/cover_stereo.stl
164.4 x 212.3 x 87.9

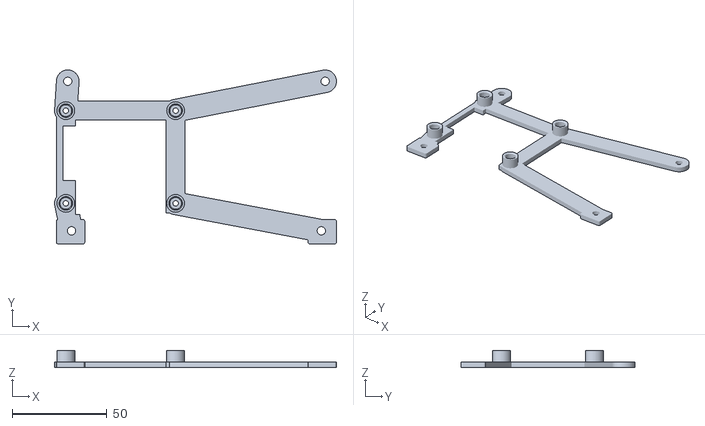
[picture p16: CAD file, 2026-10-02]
hardware/3d/battery_lidar_mount/pi_base.stl
149.0 x 92.0 x 9.00

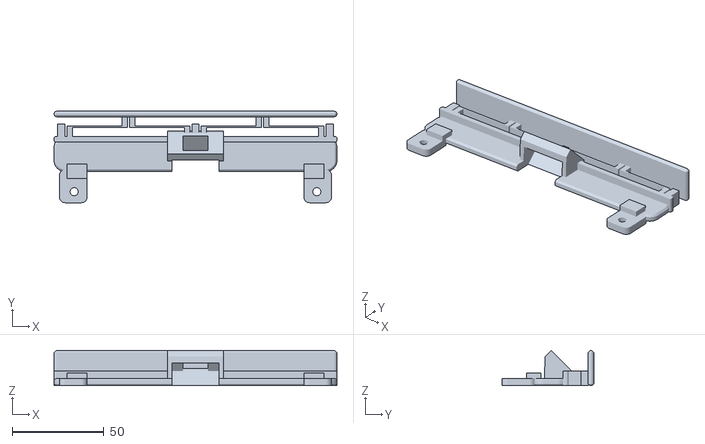
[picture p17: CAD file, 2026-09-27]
hardware/3d/battery_lidar_mount/bumper.stl
154.0 x 49.8 x 19.2

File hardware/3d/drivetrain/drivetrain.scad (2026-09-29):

// AI-CAR の駆動系（購入品）の参考モデル: メカナムホイール・520 モーター・37 mm モーターの台 ×4
// 印刷しない。組み立て図に重ねて表示するためだけの形（寸法は OSOYOO の図面）
// 座標は天板と同じ（X 左右: 天板の左端 0、Y 前後: 天板の後端 0・+Y が前、Z: 天板の上面 0）
// part = "all" / "wheels" / "motors"（モーター・軸・カップリング） / "holders"（モーターの台）
part = "all";

plate_w = 154;
plate_l = 200;
plate_t = 2;
cov_side = 2.7;           // カバーの左右の壁の外側（天板の端から外へ）。test_stand.scad と同じ

// メカナムホイール（OSOYOO 2019018100.jpg）
wheel_d = 80.59;
wheel_w = 39.1;
wheel_hex = 6.5;          // 中心の六角穴
wheel_in = 4;             // カバーの壁の外側から車輪の内側の面まで（仮定。test_stand.scad と同じ）
rollers = 8;
roller_d = 17;            // ローラーの太さ（図面にないので見た目の値）

// 37 mm モーターの台（2018003600.jpg）: L 字、板厚 2、底 42 × 40、立ち上がり 46、軸は底から 27
hold_t = 2;
hold_l = 42;
hold_w = 40;
hold_h = 46;
hold_axis = 27;
hold_hole0 = 9.5;         // 立ち上がりの外側の面から近い方の穴まで（穴の間隔 24 × 30）
hole_x = 12;              // 天板の穴（1st_layer.dwg: X 12 / 36、Y 37 / 67）
wheel_axle = 52;          // 車軸（天板の前後の端から）。穴 Y 37 / 67 の中心

// 520 モーター（2024005900.pdf）: 全長 58（うちギア箱 Ø37 × 24、モーター Ø32.8）、ボス Ø12 × 6、軸 Ø4 × 16
gear_d = 37;
gear_l = 24;
mot_d = 32.8;
mot_l = 58;
boss_d = 12;
boss_l = 6;
shaft_d = 4;
shaft_l = 16;
coup_d = 12;              // カップリング（図面にないので見た目の値）。車輪の中は六角 6.5 mm

face_x = hole_x - hold_hole0;        // 台の立ち上がりの外側の面（左）
motor_x = face_x + hold_t;           // ギア箱の前の面
axle_z = -plate_t - hold_axis;       // 軸の高さ
wheel_x0 = -cov_side - wheel_in;     // 車輪の内側の面（左）

$fn = 48;

// 左前の 1 組を作り、左右・前後に鏡像で並べる
module corners() {
    for (mx = [0, 1], my = [0, 1])
        translate([mx * plate_w, my * plate_l, 0]) mirror([mx, 0, 0]) mirror([0, my, 0])
            translate([0, wheel_axle, 0]) children();
}

module wheel(hand = 1) {
    translate([wheel_x0 - wheel_w / 2, 0, axle_z]) rotate([0, 90, 0]) {
        difference() {
            union() {
                for (s = [-1, 1]) translate([0, 0, s * (wheel_w / 2 - 1.5)]) cylinder(d = wheel_d - 16, h = 3, center = true);
                cylinder(d = 22, h = wheel_w - 2, center = true);
            }
            cylinder(d = wheel_hex / cos(30), h = wheel_w + 2, center = true, $fn = 6);
        }
        intersection() {
            cylinder(d = wheel_d, h = wheel_w, center = true, $fn = 96);
            for (i = [0 : rollers - 1]) rotate([0, 0, i * 360 / rollers])
                translate([wheel_d / 2 - roller_d / 2, 0, 0]) rotate([hand * 45, 0, 0])
                    scale([1, 1, 2.6]) sphere(d = roller_d, $fn = 18);
        }
    }
}

module motor() {
    translate([0, 0, axle_z]) rotate([0, 90, 0]) {
        translate([0, 0, motor_x]) cylinder(d = gear_d, h = gear_l);
        translate([0, 0, motor_x + gear_l]) cylinder(d = mot_d, h = mot_l - gear_l);
        translate([0, 0, motor_x - boss_l]) cylinder(d = boss_d, h = boss_l);
        translate([0, 0, motor_x - shaft_l]) cylinder(d = shaft_d, h = shaft_l);
        translate([0, 0, wheel_x0]) cylinder(d = coup_d, h = motor_x - boss_l - wheel_x0);
        translate([0, 0, wheel_x0 - wheel_w / 2]) cylinder(d = wheel_hex / cos(30) - 0.2, h = wheel_w / 2, $fn = 6);
    }
}

module holder() {
    difference() {
        union() {
            translate([face_x, -hold_w / 2, -plate_t - hold_t]) cube([hold_l, hold_w, hold_t]);
            translate([face_x, 0, 0]) rotate([0, 90, 0]) linear_extrude(hold_t) hull() {
                translate([plate_t, -hold_w / 2]) square([1, hold_w]);
                translate([-axle_z, 0]) circle(r = hold_h - hold_axis);
            }
        }
        translate([face_x - 1, 0, axle_z]) rotate([0, 90, 0]) cylinder(d = boss_d + 1, h = hold_t + 2);
    }
}

if (part == "all" || part == "wheels") color("#474d57") corners() wheel();
if (part == "all" || part == "motors") color("#b9c2cc") corners() motor();
if (part == "all" || part == "holders") color("#2f3440") corners() holder();

echo(face_x = face_x, motor_end = motor_x + mot_l, axle_z = axle_z, wheel_bottom = axle_z - wheel_d / 2);

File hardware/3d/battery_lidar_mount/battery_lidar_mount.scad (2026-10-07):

// AI-CAR バッテリー 2 個 + RPLIDAR A1M8 マウント
// 座標: 天板 154 x 200 mm の左下角が原点。X = 横幅方向、Y = 前後方向（Y=200 側が前 / LiDAR 側）
// 天板の穴位置は Y 方向に対称なので、前後どちら向きでも同じ穴に合う。
//
// 出力: openscad -D 'part="box"' -o box.stl battery_lidar_mount.scad
//       openscad -D 'part="lid"' -o lid.stl battery_lidar_mount.scad
//       openscad -D 'part="pi_base"' -o pi_base.stl battery_lidar_mount.scad
//       openscad -D 'part="cam_mount"' -o cam_mount.stl battery_lidar_mount.scad（カメラの板。裏を下にした向き）
//       （2 眼カメラ用は -D 'front_cam="stereo"' を足して cam_mount_stereo.stl / cover_stereo.stl）
//       openscad -D 'part="bumper"' -o bumper.stl battery_lidar_mount.scad（前後共通、2 個印刷）
//       openscad -D 'part="cover"' -o cover.stl battery_lidar_mount.scad（上面カバー、上面を下にした向き）

part = "assembly"; // "box" | "lid" | "pi_base" | "cam_mount" | "bumper" | "cover" | "assembly"
show_cables = false;  // 組立図に配線経路の目安を描く
show_cover = false;   // 組立図に上面カバーを描く
front_cam = "wide";   // 前のカメラ: "wide"（Camera Module 3 Wide、1 眼）| "stereo"（USB 2 眼）。板・カバーの窓・組立図が変わる（ふたは共通）

$fn = 48;

// ---- 天板（ユーザー提供の CAD 図面）----
plate_w = 154;
plate_l = 200;
plate_t = 2;               // 実測
plate_holes = [[11, 11], [143, 11], [11, 189], [143, 189],
               [9, 90], [145, 90], [9, 110], [145, 110]];
mount_holes = [[11, 189], [143, 189], [9, 110], [145, 110]];
mount_hole_d = 4.4;

// 天板の上に頭が出ているモーター取付のネジ（図面: 28 x 28 mm の範囲 4 か所、左右の端から 7 mm、前後の端から 38 mm、高さ 3 mm）
// 上に載る部品（前は箱、後ろ左はラズパイ台）の底にくぼみを付けて逃げる
motor_scr_sq = 28;
motor_scr_h = 3;
motor_scr_pts = [[7, 38], [plate_w - 7 - motor_scr_sq, 38],
                 [7, plate_l - 38 - motor_scr_sq], [plate_w - 7 - motor_scr_sq, plate_l - 38 - motor_scr_sq]];  // 各範囲の左後ろの角
recess_clr = 0.5;         // ネジとくぼみのすき間（横と上）
recess_roof = 1.5;        // くぼみの上に残す厚さ
recess_rim = 1.5;         // くぼみの周りの縁
recess_t = motor_scr_h + recess_clr + recess_roof;  // くぼみの上の部品の厚さ

module motor_recess() {
    for (p = motor_scr_pts) translate([p[0] - recess_clr, p[1] - recess_clr, -1])
        cube([motor_scr_sq + 2 * recess_clr, motor_scr_sq + 2 * recess_clr, 1 + motor_scr_h + recess_clr]);
}

module motor_recess_pad(pts) {
    m = recess_clr + recess_rim;
    for (p = pts) rrect(p[0] - m, p[1] - m, p[0] + motor_scr_sq + m, p[1] + motor_scr_sq + m, 2, recess_t);
}

// ---- ネジ穴 ----
// "tap": ネジを直接ねじ込んで、ネジ自身にねじ山を切らせる下穴（M2〜M3 のねじ山は FDM ではきれいに出ないため）
// "insert": 熱圧入インサート（真鍮）を入れる穴
screw_mode = "tap";
function tap_d(m) = m == 2 ? 1.7 : m == 2.5 ? 2.1 : 2.5;
function insert_d(m) = m == 2 ? 3.2 : m == 2.5 ? 3.6 : 4.0;
function nut_hole_d(m) = screw_mode == "insert" ? insert_d(m) : tap_d(m);
function clear_d(m) = m + 0.4;
function head_d(m) = m == 2 ? 4.4 : m == 2.5 ? 5.2 : 6.2;

// 入口を z = 0 とし、-Z 方向へ depth の深さのねじ込み穴（入口に面取り）
module screw_hole(m, depth, d = undef) {
    d = is_undef(d) ? nut_hole_d(m) : d;
    translate([0, 0, -depth]) cylinder(d = d, h = depth + 0.01);
    translate([0, 0, -0.6]) cylinder(d1 = d, d2 = d + 1.2, h = 0.61);
    cylinder(d = d + 1.2, h = 1);
}

// z = 0 から +Z 方向へ h の厚さを通す穴。cb > 0 なら下側から深さ cb の座ぐり（ネジ頭を中に沈める）
module clear_hole(m, h, cb = 0) {
    translate([0, 0, -1]) cylinder(d = clear_d(m), h = h + 2);
    if (cb > 0) translate([0, 0, -1]) cylinder(d = head_d(m), h = cb + 1);
}

// ---- バッテリー（CIO SMARTCOBY Pro SLIM 35W）x 2 段重ね ----
bat_x = 98.2;   // 長辺（実測。X 方向に置く。ポートのある短辺が開口側を向く）
bat_y = 66.8;   // 短辺（実測）
bat_z = 16.2;
bat_n = 2;
clr = 0.4;      // 前後の片側のすき間
clr_x = 0.3;    // 左右の片側のすき間

// ---- 箱 ----
wall = 2.5;
wall_y = 3.8;   // 前後の壁（外形 75.2 mm を保ち、内側へ厚くしてすき間を clr にする）
floor_t = recess_t;   // 前のモーターのネジの上に載るので、くぼみの分だけフランジより厚い
flange_t = 3;
flange_y0 = 104;
flange_y1 = 196;
flange_x0 = 3;
flange_x1 = 151;
flange_r = 4;
open_end = "right";   // バッテリー出し入れ・ケーブル側: "right"(+X) / "left"(-X)
strap_w = 12;         // 面ファスナー / 結束バンド用スロットの高さ
strap_len = 3;        // スロットの幅（ストラップ厚み方向）

in_x = bat_x + 2 * clr_x;
in_y = bat_y + 2 * clr;
in_z = bat_n * bat_z + 1.0;
box_x = in_x + 2 * wall;
box_y = in_y + 2 * wall_y;
box_h = floor_t + in_z;
box_cx = plate_w / 2;
box_cy = (flange_y0 + flange_y1) / 2;
box_x0 = box_cx - box_x / 2;
box_y0 = box_cy - box_y / 2;
// 開口と反対側の端の壁を内側へ厚くする量（実物の長手方向のすき間 約 2 mm を 2 mm のプレートでふさいで確認）
end_fill = 2;
in_x0 = box_x0 + wall + (open_end == "right" ? end_fill : 0);  // バッテリーを入れる空間の左端

// 上のバッテリーの残量表示（ロゴの面を上、ポートを右にして入れる）
// ポートの短辺から 7〜20 mm、ロゴの面でポートを上にしたときの右の長辺から 9〜21 mm（21 は写真からの推定）
bat_disp = [7, 20, 9, 21];
disp_lid_m = 1;           // ふたの窓の余白
disp_cov_m = 2;           // カバーの窓の余白（斜めから見る分）
function disp_rect() = let(x1 = in_x0 + clr_x + bat_x, y0 = box_y0 + wall_y + clr)
    [x1 - bat_disp[1], y0 + bat_disp[2], x1 - bat_disp[0], y0 + bat_disp[3]];

// ふた固定用ボス（箱の外側 4 隅、M3 タッピング）
boss_d = 8;
boss_pts = [[box_x0 - boss_d / 2 + 1.5, box_y0 + 6],
            [box_x0 + box_x + boss_d / 2 - 1.5, box_y0 + 6],
            [box_x0 - boss_d / 2 + 1.5, box_y0 + box_y - 6],
            [box_x0 + box_x + boss_d / 2 - 1.5, box_y0 + box_y - 6]];
// 中を抜くボス（boss_pts の番号）。開口側の後ろの角は、バッテリーに差す L 字の USB プラグが当たるので、上下 boss_keep だけ残す
boss_open = [1];
boss_keep = 5;            // 残す高さ（下はフランジの上から、上は箱の上端から）
boss_tie_l = 20;          // 上の部分を、後ろ（前）の壁の外側に沿わせて留める長さ
boss_tie_t = 2;           // 壁の外側に足す厚さ

// ---- 2 眼カメラ（3D USB Camera 3D-1080P02、基板 80 x 17 mm）: ふたの前、LiDAR のモーターの下に、USB 端子を上にして立てる ----
// 四隅の M2 の穴で、ふたの前端の面に当てる板（cam_mount.stl）に留める。板は左右の耳を、ふたの前端の柱 2 本に M3 で留める
// USB は基板の上の端から L 字のプラグを上から差し、ケーブルを後ろへ曲げて、ふたの上を Pi へ通す
scam_board = [80, 17, 1.6];   // 幅 x 高さ（実測）x 厚さ（仮）
scam_baseline = 60;           // 左右のレンズの中心の間隔（約 60 mm）
scam_lens_d = 18;             // レンズのいちばん太い所（実測）
scam_lens_l = 26;             // 基板の表からレンズの先まで（実測）
scam_lens_z = 0;              // 仮: 基板の上下の中心からレンズの中心まで
scam_hole_in = 1.5;           // 四隅の M2 の穴の中心の、基板のふちからの距離（実測）
scam_back_h = 2;              // 基板の裏の部品の高さ（実測）
scam_usb_room = 15;           // 基板の上端から LiDAR のモーターの下端まで（L 字の USB-C プラグの分）
scam_mnt_t = 2.5;             // 板の厚さ
scam_so = scam_back_h + 0.5;  // 板から基板の裏までの支柱の長さ
scam_so_d = 4.6;              // 支柱の太さ
scam_hole_d = 2.5;            // 支柱と板の M2 の下穴（1.7 では印刷で約 0.5 mm につぶれたため）
scam_ear_w = 8;               // 板の左右の耳（ふたの柱に M3 で留める）の幅
scam_lpost_d = 6;             // ふたの柱の奥行き
scam_slot_clr = 1.5;          // カバーの窓とレンズのすき間（片側）

// ---- Camera Module 3 Wide（SC0874、横 102° / 縦 67°）: 2 眼と同じ板の位置に、FPC の端子を上にして（上下逆さまに）立てる ----
// 寸法は公式の図面 RP-008155-DS-1（camera-module-3-wide-mechanical-drawing）。届いたら、レンズの長さと裏の端子の高さを実測して直す
// M2 の穴 4 個で板の支柱に留める。FPC は基板の上の端の裏の端子から上へ出し、後ろへ折って板の上とふたの上を Pi へ通す
wcam_board = [25, 23.862, 1.12];  // 幅 x 高さ x 厚さ
wcam_hole_dx = 21;                // 左右の M2 の穴（Ø2.2）の間隔
wcam_hole_z = [2.0, 14.5];        // M2 の穴の中心の、基板の下の端（FPC と反対）からの高さ
wcam_lens_z = 14.4;               // レンズの中心の、基板の下の端からの高さ
wcam_lens_box = 10.8;             // レンズの台（四角）の幅
wcam_lens_box_l = 4.2;            // 基板の表からレンズの台の前まで（図面の 8.3 − 4.07）
wcam_lens_d = 6.95;               // レンズの先の太さ
wcam_lens_l = 8.3;                // 基板の表からレンズの先まで（図面の 8.3）
wcam_conn = [20, 3.0, 5.71];      // 裏の FPC の端子（幅は仮、高さは図面の 12 − 8.3 − 1.12 より大きめ、上下は図面の 5.71）
wcam_so = 4;                      // 板から基板の裏までの支柱の長さ（端子の高さ 3 mm + 1 mm）
wcam_hfov = 102;
wcam_vfov = 67;
wcam_win_clr = 1.5;               // カバーの窓の、レンズの先のまわりのすき間
wcam_win_deg = 4;                 // カバーの窓の、画角の線の外へ足す角度（片側）
fpc_w = 16;                       // フラットケーブルの幅（15 ピンの側）
wcam_nut_af = 4.4;                // 板の裏の M2 ナット（二面幅 4 mm、厚さ 1.6 mm）のくぼみの二面幅
wcam_nut_d = 1.8;                 // くぼみの深さ（ナットが板の裏から出ない）
wcam_relief_d = 6.5;              // 板の裏の M2 の後ろの、ふた・箱の逃げ穴の太さ（ナットの角 4.6 mm + すき間）
wcam_relief_l = 4;                // 逃げ穴の深さ（板の裏から後ろへ。M2 x 10 mm の先 2.4 mm も入る）

tie_w = 4.5;              // 結束バンド（幅 3.6 mm まで）を通すトンネル
tie_h = 2;

// ---- ラズパイ台（Raspberry Pi 5、天板の後ろ側）----
pi_mount_holes = [[11, 11], [143, 11], [9, 90], [145, 90]];
pi_cx = 47;               // 基板中心。電源ボタンの短辺（-X）をカバーの左の壁に寄せ、USB / LAN 側（+X）を広く空ける
pi_cy = 50;
pi_board = [85, 56];
pi_hole_dx = 58;
pi_hole_dy = 49;
pi_hole_off = 3.5;        // 電源ボタン側の短辺からの距離（USB / LAN は +X 側）
pi_btn_y = [0, 18];       // 仮: 電源ボタンを探す範囲（-X の短辺に沿って、USB-C の長辺（-Y）から）。カバーの左の壁の穴になる
pi_btn_z = [-2, 9];       // 仮: 穴の高さ（Pi の基板の下面から）
pi_so_hole_d = 6.2;       // 幅 5 mm の M2.5 六角支柱を差し込む丸い穴（六角の角と角の間 5.77 mm + 0.43 mm）
pi_so_in = 5;             // 支柱を差し込む深さ
pi_so_l = 5;              // 支柱の長さ（Pi の基板の下に出ている部分。仮の値で、Pi の高さの図とカバーの確認だけに使う）
pi_boss_d = pi_so_hole_d + 2 * 1.6;
pi_boss_h = 6;
pi_screw_cb = 2;          // 台の裏から支柱を留める M2.5 のネジの頭を沈める深さ
pi_base_t = 3;
pi_z = pi_base_t + pi_boss_h - pi_so_in + pi_so_l;   // Pi の基板の下面
pi_stack_h = 45;          // Pi 5 + AI HAT+ + Motor HAT の 3 段（実測。台のぶん高くなる側で見積もる）
pi_pts = [for (dx = [0, pi_hole_dx], dy = [0, pi_hole_dy])
          [pi_cx - pi_board[0] / 2 + pi_hole_off + dx, pi_cy - pi_hole_dy / 2 + dy]];
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

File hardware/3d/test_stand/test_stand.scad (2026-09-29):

// AI-CAR の試験台: カバーとバンパーを付けたまま、天板の 4 隅の下面を受けて車輪を床から浮かせる
// 1 個の部品: 4 隅の柱と左右の位置決めの壁を、中抜き（斜めの格子）の床板 10 mm でつなぐ
// 座標は天板と同じ（X 左右: 天板の左端 0、Y 前後: 天板の後端 0・+Y が前、Z: 天板の上面 0）
// part = "stand"（印刷用） / "view"（車体と重ねた図）
part = "stand";

use <../battery_lidar_mount/battery_lidar_mount.scad>

// ---- 車体（battery_lidar_mount.scad と同じ値）----
plate_w = 154;
plate_l = 200;
plate_t = 2;
cov_in = 0.3;             // カバーの左右の壁の内側（天板の端から外へ）
cov_side = cov_in + 2.4;  // カバーの左右の壁の外側。壁の下端は天板の下面
wheel_axle = 52;          // 車軸（天板の前後の端から）。OSOYOO のシャーシ 1 段目の図面で、モーターの台（37 mm 用）の穴が Y 37 / 67 mm。台の幅 40 mm の中心に軸
wheel_d = 80.59;          // 車輪の直径（OSOYOO のメカナムホイールの図面）
wheel_w = 39.1;           // 車輪の幅（同じ図面）
deck_floor = 70;          // 床から天板の下面まで（実測。車輪が床に着いた状態。図面からの計算では 40.3 + 27 = 67.3 mm）
wheel_in = 4;             // カバーの左右の壁の外側から車輪の内側の面まで（仮定。実測して合わせる）

// ---- 試験台 ----
st_h = 80;                // 床から天板の下面（受け面）まで
st_clr = 1;               // 車体とのすき間
pad_x = 40;               // 受け面の左右の幅（天板の端から内側へ）。天板の下のモーターの台は Y 32 mm から後ろなので当たらない
pad_x0 = st_clr - cov_in;  // 受け面の外側の端（カバーの壁の内側から 1 mm）
pad_y = wheel_axle - wheel_d / 2 - st_clr;  // 受け面の奥行き（天板の端から車輪の手前まで）
wall_t = 3;               // 位置決めの壁の厚さ
wall_up = 6;              // 壁の上端（天板の上面から）。カバーの左右の壁の外側にかぶせる
base_t = 10;              // 床板の厚さ
base_rim = 8;             // 床板の外周の枠の幅
rib = 5;                  // 床板の斜めの格子のリブの幅
cell = 32;                // 格子のピッチ（ひし形の穴の対角線 + リブ）
gus_l = 22;               // 柱の内側の三角の補強の長さ（Y）と高さ（床板の上から）
gus_t = 6;
edge = 1;
// 天板の 4 隅の穴（Ø4.4。上の部品を留めるネジの先・ナット）を受け面にくぼみでよける
corner_holes = [[11, 11], [plate_w - 11, 11]];
nut_d = 12;               // くぼみの直径（M4 のナットの角 8.1 mm・ワッシャー Ø9 より大きく）
nut_h = 12;               // くぼみの深さ（天板の下面から）

z_floor = -plate_t - st_h;
z_base = z_floor + base_t;
lift = st_h - deck_floor;  // 車輪が浮く量
x_wall0 = -cov_side - st_clr - wall_t;
x_wall1 = plate_w + cov_side + st_clr + wall_t;
y0 = -st_clr;             // 床板の後ろの端（天板の後端より 1 mm 後ろ。後ろのバンパーの下端は床から約 70 mm）
y1 = plate_l + st_clr;
wheel_y = [wheel_axle - wheel_d / 2 - st_clr, wheel_axle + wheel_d / 2 + st_clr];  // 前後の車輪の範囲（天板の端から）
assert(pad_y >= 10, "車輪が大きく、受け面が 10 mm 取れない");
assert(wheel_in >= st_clr, "床板が車輪の下に入る（床板の上面は浮いた車輪の下端とほぼ同じ高さ）");

module rbox(p0, p1, r = edge) {
    translate([p0[0], p0[1], p0[2]]) hull()
        for (x = [r, p1[0] - p0[0] - r], y = [r, p1[1] - p0[1] - r])
            translate([x, y, 0]) cylinder(r = r, h = p1[2] - p0[2], $fn = 16);
}

// 床板の外形（前後の端は左右いっぱい、車輪のある間は天板の幅まで）
module base_outline() {
    offset(r = 3) offset(delta = -3) union() {
        translate([x_wall0, y0]) square([x_wall1 - x_wall0, pad_y - y0]);
        translate([x_wall0, plate_l - pad_y]) square([x_wall1 - x_wall0, y1 - plate_l + pad_y]);
        translate([0, y0]) square([plate_w, y1 - y0]);
    }
}

// 柱の下と補強の下は穴をあけない
module base_solid_zone() {
    for (c = corners()) translate([c[0] - 4, c[1] - 4]) square([c[2] - c[0] + 8, c[3] - c[1] + 8 + gus_l]);
}

// 4 隅の柱の範囲 [x0, y0, x1, y1]（後ろの 2 隅は Y を反転して使う）
function corners() = [[x_wall0, y0, pad_x, pad_y], [plate_w - pad_x, y0, x_wall1, pad_y]];

module base() {
    translate([0, 0, z_floor]) linear_extrude(base_t) difference() {
        base_outline();
        difference() {
            offset(delta = -base_rim) base_outline();
            // 斜めの格子のリブ（ひし形の穴のあいだ）
            for (i = [-8 : 8]) {
                translate([plate_w / 2 + i * cell / sqrt(2), plate_l / 2]) rotate(45) square([rib, 400], center = true);
                translate([plate_w / 2 + i * cell / sqrt(2), plate_l / 2]) rotate(-45) square([rib, 400], center = true);
            }
            // 中心線のリブ（前後）
            translate([plate_w / 2, plate_l / 2]) square([rib, 400], center = true);
            for (m = [0, 1]) translate([0, plate_l / 2]) mirror([0, m]) translate([0, -plate_l / 2]) base_solid_zone();
        }
    }
}

// 後ろの 2 隅（Y が小さい側）
module corner_posts() {
    difference() {
        corner_posts_solid();
        for (h = corner_holes) translate([h[0], h[1], -plate_t - nut_h]) cylinder(d = nut_d, h = nut_h + 0.01, $fn = 48);
    }
}

module corner_posts_solid() {
    for (s = [0, 1]) {
        c = corners()[s];
        // 柱（上面が受け面。天板の外はカバーの壁の下端とバンパーから 1 mm 下げる）
        rbox([s ? plate_w - pad_x : pad_x0, 0, z_floor], [s ? plate_w - pad_x0 : pad_x, pad_y, -plate_t]);
        rbox([c[0], y0, z_floor], [c[2], pad_y, -plate_t - st_clr]);
        // 位置決めの壁（カバーの左右の壁の外側に 1 mm あけてかぶせる）
        wx = s ? plate_w + cov_side + st_clr : x_wall0;
        rbox([wx, y0, z_floor], [wx + wall_t, pad_y, wall_up]);
        // 柱の内側の三角の補強（天板の幅の中、車輪より内側）
        gx = s ? plate_w - pad_x / 2 : pad_x / 2;
        translate([gx - gus_t / 2, pad_y - 0.01, z_base - 0.01]) rotate([90, 0, 90]) linear_extrude(gus_t)
            polygon([[0, 0], [gus_l, 0], [0, gus_l]]);
    }
}

module stand() {
    base();
    corner_posts();
    translate([0, plate_l, 0]) mirror([0, 1, 0]) corner_posts();
}

module car() {
    plate();
    color("royalblue") box();
    color("orange") translate([0, 0, 38.4]) lid();
    color("seagreen") pi_base();
    color("dimgray") both_bumpers();
    color("#3c4452", 0.5) cover();
}

module wheels_ghost() {
    for (y = [wheel_axle, plate_l - wheel_axle], s = [0, 1])
        color("#222", 0.7) translate([s ? plate_w + cov_side + wheel_in + wheel_w / 2 : -cov_side - wheel_in - wheel_w / 2, y, -plate_t - deck_floor + wheel_d / 2])
            rotate([0, 90, 0]) cylinder(d = wheel_d, h = wheel_w, center = true);
}

if (part == "stand") translate([0, 0, -z_floor]) stand();
if (part == "view") {
    translate([0, 0, lift]) { car(); wheels_ghost(); }
    color("#d98c3a") translate([0, 0, lift]) stand();
}
if (part == "view_raised") { car(); wheels_ghost(); color("#d98c3a") stand(); }

echo(pad = [pad_x, pad_y], lift = lift, stand_size = [x_wall1 - x_wall0, y1 - y0, st_h + plate_t + wall_up]);

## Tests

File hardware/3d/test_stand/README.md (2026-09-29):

# AI-CAR 試験台（test_stand）

車体を載せて車輪を床から浮かせ、モーター・エンコーダー・センサーを走らせずに試すための台です。

- カバーとバンパーを付けたまま載せられます
- 天板の 4 隅の下面（左右 40 mm × 前後 10.7 mm）で受けます。受け面は床から 80 mm（天板の下面の高さ。車輪が床に着いたときは約 70 mm なので、車輪は約 10 mm 浮きます）
- 車体とのすき間は 1 mm です。受け面の外側はカバーの左右の壁の下端（天板の下面の高さ）から 1 mm 下げ、左右の位置決めの壁はカバーの壁の外側から 1 mm あけています。バンパー・カバー・車輪（仮の寸法）とは 1 mm 以上離れています（OpenSCAD で確認）
- 4 隅の柱を厚さ 10 mm の床板でつないだ 1 個の部品です（167.4 × 202 × 88 mm。K1C の 220 × 220 mm に入る）
- 床板は中抜きです。外周の枠 8 mm、斜めの格子のリブ 5 mm（ピッチ 32 mm）と前後の中心線のリブで、ねじれと曲げに強くしています。柱の下は穴をあけず、柱の内側に三角の補強を付けています
- 車輪のある所（前後の端から 10.7〜93.3 mm）の床板は天板の幅までにして、車輪の下に入らないようにしています。床板の上面は浮いた車輪の下端とほぼ同じ高さです

| 載せた図 | 前から | 横から | 部品（印刷する向き） | 床板（真上から） |
|---|---|---|---|---|
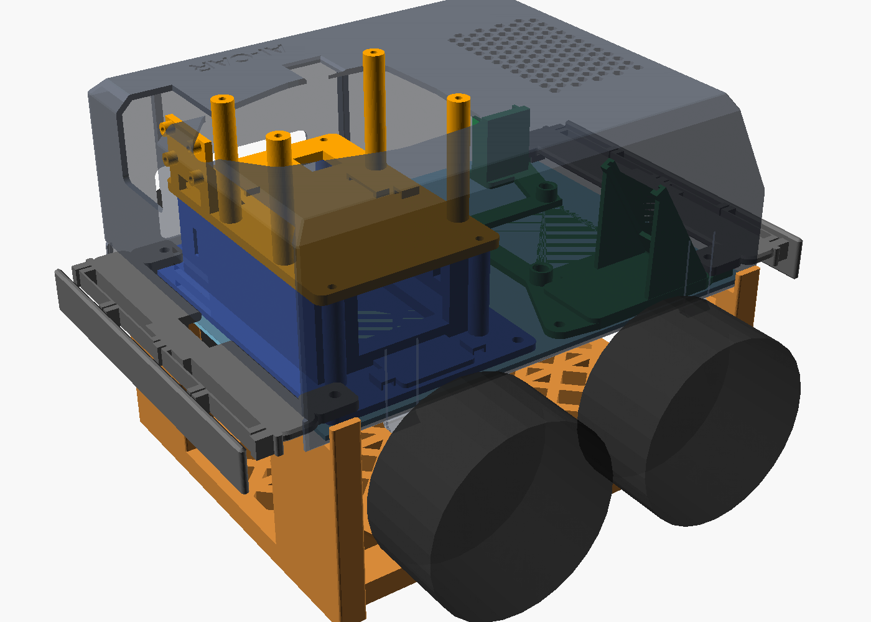
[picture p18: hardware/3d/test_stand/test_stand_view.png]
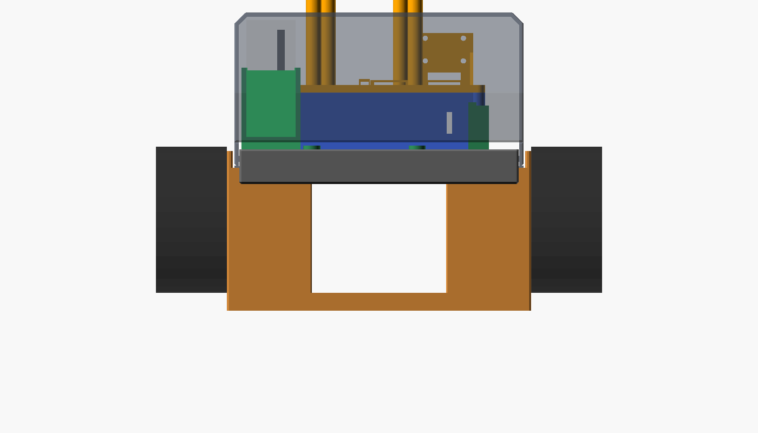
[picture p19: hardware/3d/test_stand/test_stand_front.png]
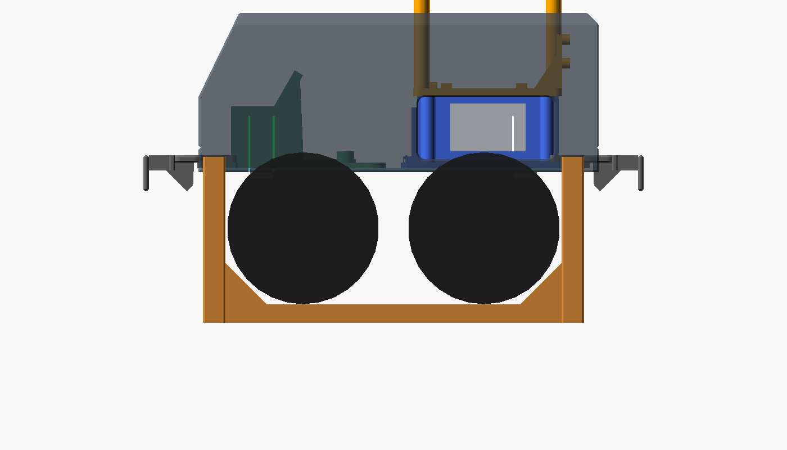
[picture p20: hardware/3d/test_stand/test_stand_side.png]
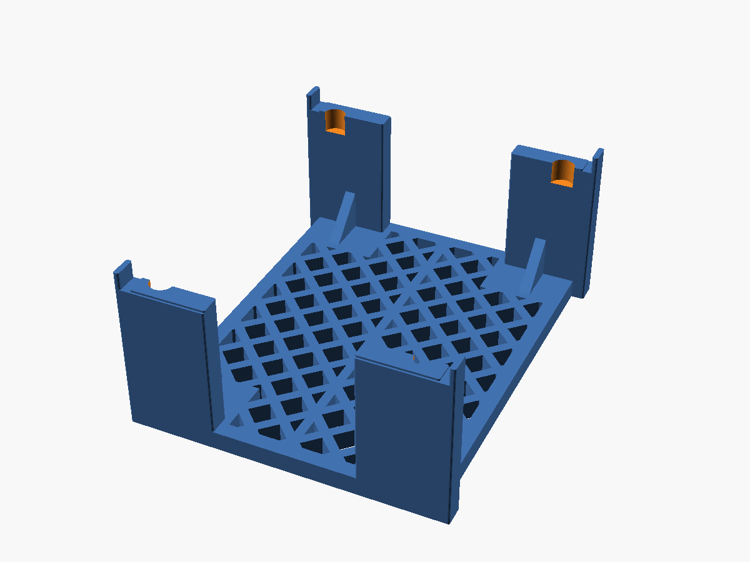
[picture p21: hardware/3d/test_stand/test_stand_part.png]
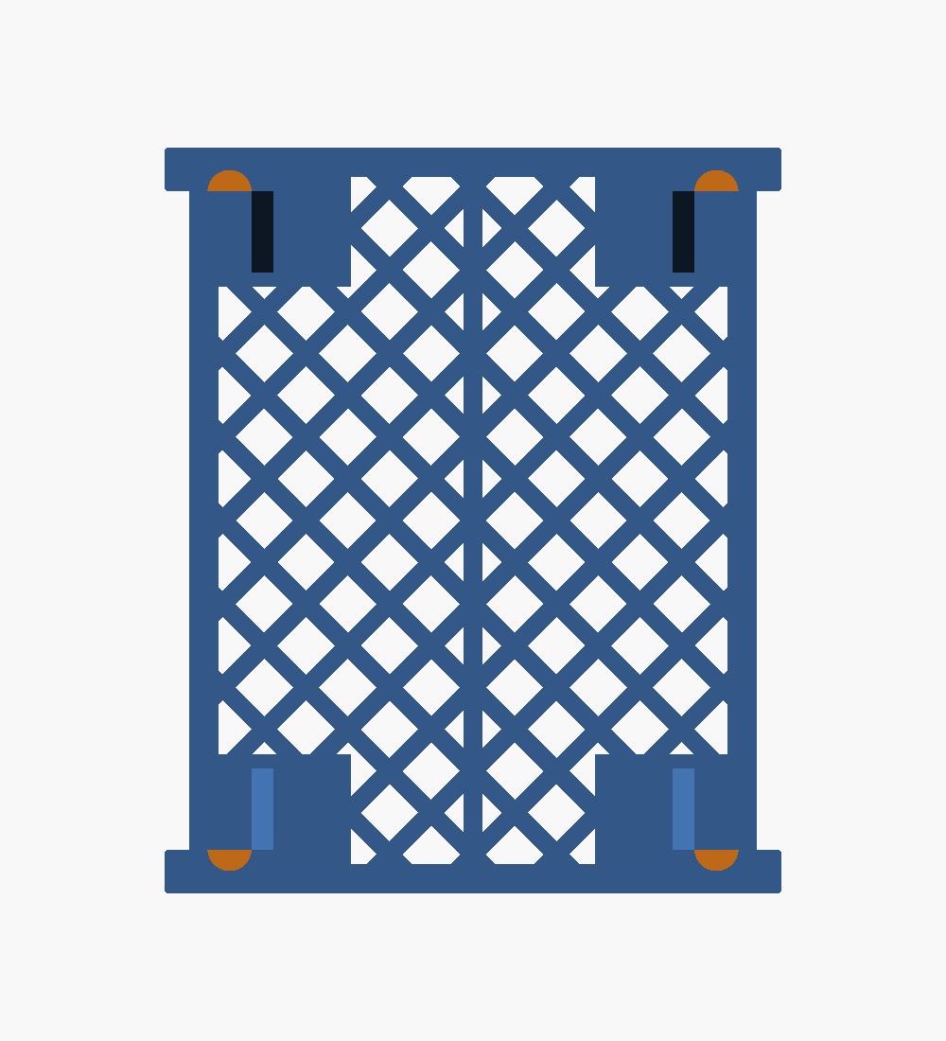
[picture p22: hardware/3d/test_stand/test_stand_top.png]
|  |  |  |  |  |

ダッシュボードの 3D プリントタブでは、部品の「試験台」と「組み立て図（カバー付き・試験台）」で回して見られます。

## 印刷

- `test_stand.stl` × 1。床板を下にして、サポートなし
- PLA / PETG、壁 3 周、インフィル 20 % 程度

## 使い方

1. 平らな床に置きます
2. 車体を上から下ろし、左右の壁の間に入れて、天板の 4 隅を受け面に載せます
3. 前後方向は止めていません（摩擦だけ）。急な加減速のテストをするときは、手で押さえてください

## 注意

- 落下防止センサー（VL53L1X）を配線したあとは、台の上では床が遠くなるので「段差」と判定され、前進・後退が止まります。台の上で走らせるときは `cliff_guard` を切ってください
- 車輪の内側の面（カバーの壁の外側から 4 mm、`wheel_in`）は仮の値です（カップリングの長さが資料にない）。受け面と位置決めの壁は車輪より前後の外にあるので、この値では当たりは変わりません
- 受け面の天板の 4 隅の穴（Ø4.4、X 11 / 143 mm・Y 11 / 189 mm）の下に、Ø12 × 深さ 12 mm のくぼみを付け、上の部品を留めるネジの先・ナット（M4 のナットの角 8.1 mm）をよけています。ナットより大きいもの（スペーサーなど）が付いているときは `nut_d`・`nut_h` を直してください

## 車輪と車軸の寸法の出どころ

部品リスト（OSOYOO 520 エンコーダー付きモーター ×4、メカナムホイール ×4）の製品の資料から取りました（[OSOYOO FlexiRover 520 モーター版のページ](https://osoyoo.com/2024/08/26/osoyoo-flexirover-basic-robot-car-for-mega2560-running-520-motor-with-mecanum-wheel-model-2024007400/)にある図面）。

| 値 | 寸法 | 資料 |
|---|---|---|
| `wheel_d` / `wheel_w` | 直径 80.59 mm、幅 39.1 mm | メカナムホイールの外形図（`2019018100.jpg`） |
| `wheel_axle` | 天板の前後の端から 52 mm | シャーシ 1 段目の図面（`1st_layer.dwg`）で、モーターの台の穴 24 × 30 mm が Y 37 / 67 mm、X 12 / 36 mm。台（`2018003600.jpg`、幅 40 mm）の中心に軸がある。天板の上のモーター取付ネジの範囲（前後の端から 38〜66 mm）とも合う |
| `deck_floor` | 70 mm（実測のまま） | 図面からの計算では、軸は台の底から 27 mm 下、車輪の半径 40.3 mm なので 67.3 mm。実測と 2.7 mm 違うので、車輪は 10〜12.7 mm 浮く |

モーター（`2024005900.pdf`）は Ø37 × 長さ 72 mm、軸 Ø4（D カット）で、台の底から約 48 mm 下まで出ます。台は Y 32〜72 mm にあり、受け面（Y 10.7 mm まで）と三角の補強には当たりません。

## 作り直し

```bash
openscad -o test_stand.stl test_stand.scad
openscad -D 'part="view"' --projection=o --camera=77,100,-20,90,0,90,600 --imgsize=1400,800 --colorscheme=Tomorrow -o test_stand_side.png test_stand.scad
```

`battery_lidar_mount.scad` を `use` しているので、`part = "view"` ではカバー・バンパーなどの今の形と重ねて表示します。

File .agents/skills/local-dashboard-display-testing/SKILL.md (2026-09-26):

---
name: local-dashboard-display-testing
description: ROS 2や実機を使用せず、AI-CARダッシュボードの設定由来の表示を安全に確認する方法
---

# ローカル表示確認

## 安全境界
- 表示だけの依頼ではRaspberry PiにSSH接続しない。実機用blueprintの接続手順を実行しない。
- 代替APIは依頼者が許可した場合のみ使い、最終報告に実FastAPI/ROS統合を確認していないことを記載する。
- 表示用サーバーは127.0.0.1にbindし、制御用POST APIを提供しない。

## 起動
- パッケージルートは`src/ai_car_web`。設定はその中の`config`にある。
- ROS 2がなくても、Python標準ライブラリのHTTPサーバーと既存PyYAMLで表示確認できる。
- `/`で`static/index.html`をそのまま配信する。
- パッケージルートをPythonパスに追加し、次の実関数をGETエンドポイントに割り当てる。
  - `/api/motor_hat`: `ai_car_web.motor_hat.load_motor_hat(config/motor_hat.yaml)`
  - `/api/gpio`: `ai_car_web.gpio_pinout.build_pinout(config/gpio_pins.yaml)`
  - `/api/architecture`: `ai_car_web.architecture.load_architecture(config/architecture.yaml, {})`
  - `/api/dev_diary`: `ai_car_web.dev_diary.load_dev_diary(ai_car_web.dev_diary.find_repo(パッケージルート))`（git の記録から作る。開発日記ボタンで表示）
  - `/api/status`: `{}`。ライブテレメトリーではないことを明示する。
- WSが利用できなければUIはstatusのポーリングに切り替わる。カメラなど未提供APIの表示は対象外とする。
- 日本語が豆腐になる場合は`fonts-noto-cjk`を導入し、Chromeを再起動する。単純な再読み込みでは反映されない場合がある。

## UI導線と証拠
- 「プロジェクト説明」→「ハードウェア構成」→「配線詳細」。
- GPIOカードの下にMotor HATカードがある。モーダル内をスクロールする。
- SVG、表、割付バッジと末尾の警告注記をそれぞれ確認する。
- カードの文字が小さいため、全画面スクリーンショットに加え、computer.zoomの実解像度画像が有用。
- 録画前に`wmctrl -r :ACTIVE: -b add,maximized_vert,maximized_horz`で最大化する。

## Devin Secrets Needed
- ローカル表示確認には不要。

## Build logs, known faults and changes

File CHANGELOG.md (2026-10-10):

# CHANGELOG.md

## [Unreleased]

### Known Issues
- Motor HAT の出力故障（2026/09/25）: 12V は HAT 内まで到達し PCA9685 への指令も正しいが、M1・M3 とも駆動中の出力が 0V、緑 LED も消灯。モーター単体は正常。同型品（Adafruit 2348）へ交換予定。詳細は PROJECT_STATUS.md「既知の問題」

### Added
- スタックちゃん: パソコンの声のときは、会話の AI をそのキャラクターにする（「あなたは「ずんだもん」です」から始める `system_prompt`。前は「スタックちゃん」のまま話し方だけ足していて、「だれ？」に「スタックちゃん」と答えていた）。「だれ？」「誰の声？」には今の声の名前で答え、ネットでは調べない（`SELF_ASK`）。話し方の決まり（文の終わり・例）を強め、英語の言葉を日本語に言いかえさせ、中国語の文は読まない（`is_chinese`）。実機（10/10）: 5 人 × 6 問で全部その名前・話し方になった
- スタックちゃん: パソコンの「ネット」で調べる所を増やす。質問からパソコンの AI が検索ことばを作り（`search_words`）、Wikipedia の説明と右の表（現職・就任日）・DuckDuckGo・Google ニュースをいっしょに調べる（`wiki_info`・`ddg_info`）。調べた結果に答えがあれば言い切り、いちばん新しい日付のものを答えるようにプロンプトを直す。実機（10/10）: 「今のウクライナの首相は誰？」に約 2 秒で「セルヒー・コレツキー（2026年7月16日就任）」と答える（前は聞いた文のままニュースを検索して見つからなかった）
- スタックちゃん: ミニコンが落ちても、パソコンが直接聞き取り・返事をする。パソコン（WSL）でも `stackchan_bridge` を控えとして動かし（`--primary-url`、`pc/pc-stackchan.service`、whisper large-v3・qwen2.5:14b・VOICEVOX）、Windows の portproxy（`pc/stackchan-portproxy.ps1`）で LAN の 192.168.11.7:8000/8003 を通す。ファームウェアは、毎回ミニコンを先に試し、だめならパソコンにつなぐ（`xiaozhi-fallback-pc.patch`、カメラの送り先も今つないでいる所 `stackchan-camera-follow-server.patch`）。ミニコンがもどって約 30 秒たち、呼びかけ待ちなら、パソコンが切ってミニコンへ返す。ダッシュボードは、ミニコンの bridge が答えないときパソコンの bridge から様子を出す
- スタックちゃん: パソコンのときの「ネットにして」は XiaoZhi につながず、会話はパソコンの qwen2.5:14b のまま、天気（Open-Meteo）・ニュース（Google ニュースのトップと検索）だけミニコンが調べてプロンプトに足す（`web_info`・`pc_net`）。パソコンの声ごとに会話の話し方・性格を変える（`PC_PERSONAS`、ミニコンの Kokoro のときは足さない）。ダッシュボードの声のボタンを正式な名前にし、収まらなければ 2 行に折り返す。返事のキリル・ハングルなどの文字は消す（`FOREIGN_TEXT`）。実機（10/10）: 調べる 0.4〜1.0 秒、「今の日本の総理大臣は誰？」に調べた結果で正しく答える
- スタックちゃん: パソコンを使っているあいだの声を VOICEVOX（パソコンの CPU、`pc/voicevox.service`）にする。既定はずんだもん、ダッシュボードのパソコンのカードの「文字→声」の下のボタンで 四国めたん・春日部つむぎ・冥鳴ひまり・もち子さん にも変えられる（`POST /api/stackchan/pc_voice?speaker=` → bridge `POST :8003/pc_voice`、`pc_voice.txt` に覚える）。ネットの会話のときも、ネットの声は捨てて返事の文をこの声で読む（`relay_cloud` → `speak_own`）。パソコン・VOICEVOX が止まっていればミニコンの Kokoro。あわせて、ダッシュボードの「〜で動作中」を消し、パソコンの CPU 温度を LibreHardwareMonitor 0.9.6 の Web サーバー（localhost:8085）から読む。プロジェクト説明のシステム構成にミニコン・パソコンを足す
- ダッシュボード: Jetson / MyPC の切り替えボタンを Jetson のカードの 1 行目（タイトルの行）へ移し、MyPC を選ぶとカード全部（題名・温度・負荷率・メモリ・電源・AI の部品・動いている時間・ディスク・GPU・IP）をパソコンの値で出す（文字→声はいつも Jetson の Kokoro。更新・再起動・電源のボタンは Jetson のときだけ）。パソコンの `pc-status.service`（`jetson/stackchan_bridge/pc/pc_status.py`、Windows の値は PowerShell、GPU は nvidia-smi）が `POST /api/mypc/status` へ 1 秒ごとに送り、`/ws` の `mypc_host` で出す
- ダッシュボードの Jetson のカード「AI の部品」に「動かす所」の Jetson / MyPC ボタンを追加。スタックちゃんの聞き取りと返事を、選んだほうでする（`POST /api/stackchan/backend?to=jetson|pc` → Jetson の `stackchan_bridge` `POST :8003/backend`、`backend.txt` に覚える）。MyPC を選んでもパソコンにつながらないあいだは Jetson で動き、「MyPC につながらないので Jetson」と出す
- スタックちゃん: パソコン（WSL の Ubuntu、RTX 4080 SUPER）が動いているあいだは、聞き取りを whisper large-v3、返事を Ollama qwen2.5:14b でパソコンにさせ、止まっていれば Jetson（whisper small・qwen2.5:3b）にもどす（`stackchan_bridge` の `pc_watch`、`--pc-host`・`--pc-model`）。10 秒ごとにパソコンを見て、聞き取り・返事が 10 秒でつながらなければその回から Jetson にする。文字→声（Kokoro）は Jetson のまま。パソコン側の入れ方は `jetson/stackchan_bridge/pc/` と README。実機（10/10）: 聞き取り 0.53〜0.74 → 0.29〜0.44 秒、返事の速さ 約 16 → 約 62 文字片/秒、GPU のメモリ 16 GB のうち約 13.9 GB
- スタックちゃん: テレビの声で起きないように、呼びかけ待ちの「スタックちゃん」を「文の頭で名前を呼んだ」ときだけにする（`stackchan_bridge.is_call`）。whisper の音の注釈（「(音楽)」「(スタックちゃん)」）がある声、名前の前が 4 文字以上の声、名前のすぐあとが「の・は・が」などの声、whisper-server の `--prompt`（「台所、段ボール箱、スタックちゃん、AI-CAR。」）をそのまま返した声は呼びかけにしない。これまでの記録（呼びかけ待ちの聞き取り 348 回、うち起きた 29 回）で試すと、テレビ・雑音で起きた 16 回は 0 回になり、「スタックちゃん」「スタックちゃん。」「スタックちゃん1+1はいくつ」の 13 回はそのまま起きる
- 1 眼の低い物の表示を安定させる `mono_depth.ObjectTracker`。同じ物（横の範囲が重なり、距離の差が 0.08 m か 2 割まで）を前の枚と結び、0.5 秒に 2 回見えたら出し（`mono_confirm_count`・`mono_confirm_window_s`）、見えなくなっても 0.4 秒は前の値で出す（`mono_hold_s`、`held: true`）。距離は最近 5 回の中央値で、今の値のほうが近ければ今の値（近づいた物はすぐ近く出す）。まとめる前の値は `nearest_raw`。実機（10/9、30 秒・371 枚）: 薬の入れ物は 95 %・出たり消えたり 36 回 → 100 %・0 回、距離のゆれ（標準偏差）は 0.010 → 0.008 m。物が出るのは最大 1 枚（約 0.08 秒）おくれる。見えなくなった 0.4 秒のあいだは車が進んでも距離は変わらない（0.2 m/s で最大 8 cm 遠く出る。走行に使うときは車の進んだ量を引く）
- 物の名前を当てる YOLO（`yolov8m.hef`）を止め（`hef_path: ""`）、AI HAT+ は 1 眼の奥行きの AI だけに使う。`mono_depth_rate` 10 → 15（タイマー 0.02 秒刻みで実際は 12.5 回/秒）。YOLO がないときは AI HAT+ の負荷率を SC-Depth v3 の推論（10.7 GOP）から出す（`model_gops: 10.7`）。実機（10/9）: 1 眼の距離 約 8 → 12.5 回/秒、AI の推論 約 28 → 9 ms（前処理と見つけ方を入れて 約 21 ms）、perception_node は 1 コアの約 59 → 55 %、AI HAT+ の負荷率 4 %。薬の入れ物は 6 回中 4 回で 0.445〜0.454 m
- 1 眼の低い物: 物とする決まりを「行の床より 1.1 倍手前」から 1.07 倍にし、物の一番下を「物の下のはし（下 4 行）の奥行きに床が追いつく行」まで下げる（AI は小さい物の下のはしを床にとけこませ、上のほうしか物に見えないため）。実機の写真 8 枚（10/9、全体 102°）: 薬の入れ物（実測 0.43 m）を 8 枚とも 0.43〜0.45 m で検出（前は見つからなかった）、のりの棒（実測 0.30 m）は 0.25〜0.26 m（前は 0.30 m、近めに出る）。通り道の左右 ±0.3 m に床の誤検出は 0 回。右はしのカーテンのすそが約 0.65 m の物に出る（通り道の外）
- Camera Module 3 Wide: `camera_ros` の `sensor_mode` を `2304:1296`（2x2 まとめ・全体）に決める。決めないと 960×540 に 1536×864（真ん中だけ切り取り）が選ばれ、横の画角が 102° でなく約 79° になっていた（1 眼の距離が 0.675 倍に近く出る、YOLO の方位・LiDAR の重ねもずれる）。実機（10/9）: のりの棒 実測 0.30 m → 0.20 m だったのが 0.30 m、薬の入れ物 実測 0.43 m の床につく行も 0.43 m。30 fps のまま、camera_node は 1 コアの約 36 %。LiDAR の距離で SC-Depth の縮尺を合わせる案は、上（壁）と床で縮尺が約 3 倍ちがい、使えなかった
- 1 眼の奥行きの AI（Hailo Model Zoo の SC-Depth v3、`scdepthv3.hef`、320×256）で、床から出っぱった低い物（LiDAR の線 17.5 cm より低い物）を見つける `mono_depth.py`。`perception_node` が YOLO と同じ Hailo-8 を ROUND_ROBIN のスケジューラで分けて使い、10 回/秒で回す。AI の奥行きは縮尺がわからず遠くほど縮むので、同じ行の中央値（床）より 1.1 倍手前の所を物とし、物が床につく一番下の行を、カメラの高さ 11.2 cm と角度から床の距離に直す（1 m まで）。2 眼と同じ `/stereo/depth_status`・`/stereo/depth/compressed` に出す（`source: mono`）。実機（10/9）: のりの棒 0.20 m・薬の入れ物 0.32〜0.35 m を検出、推論 約 5.5 ms（YOLO と同時で 約 28 ms）、perception_node は 1 コアの約 59 %。`mono_depth_guard: false` で表示だけ
- 前方カメラを Camera Module 3 Wide（IMX708、`camera_ros`）に戻す。`dashboard.launch.py` の `camera_type` の既定を `picam` にし（2 眼の `stereo_camera_node`・`stereo_depth_node` は起動しない）、`perception_node` の横の画角を 102°（公称）、LiDAR から見たレンズの先を真ん前 63 mm（3D マウントの CAD 値）、URDF の `camera_link` も同じ位置にする。実機で 960×540・30.1 fps、1 枚 約 64 KB を確認
- Jetson: SSD（MAXIO MAP1202）の深いねむり（NVMe APST、0.1 秒で PS3）と Wi-Fi（RTL8822CE）の省電力を切る `jetson/power_saving`（`nvme_core.default_ps_max_latency_us=0` を extlinux.conf に、NetworkManager `wifi.powersave = 2`）。置いたままで止まる（ping は返るが SSH・AI が止まる）ことの対策の見込み。SSD は電源 20 回のうち 9 回が unsafe shutdown、Wi-Fi は 3 日 17 時間で 16 回切れていた。入れたあとの電力は 4.66 W → 4.65 W（変わらず）。
- ダッシュボード（`ai-car-dashboard.service`）の ROS の通信を UDP だけにする（`FASTDDS_BUILTIN_TRANSPORTS=UDPv4`、共有メモリ `/dev/shm` を使わない）。10/7 21:36・23:31、10/8 07:08 に、SSH が切れて 4〜11 秒後に rplidar が固まり（SIGINT で終わらず SIGKILL）、23:31 と 07:08 はそのまま CP2102 も固まった（`failed set request 0x12 status: -110`）。起動した 3 回分（約 71 時間）で SSH が切れた後 20 秒の中は合わせて約 25 分なのに、6 回の止まりのうち 4 回がその中だった。省電力は関係なし（LiDAR の USB は `power/control=on`・眠った時間 0、ASPM 切、電圧低下なし）。共有メモリの取り残しが原因かは見込み（SSH の `ros2 topic echo /scan` を SIGKILL・SIGSTOP・SIGHUP・SSH を切る、の 5 通りでは固まらなかった）。`lidar_watchdog_node` は、固まった rplidar に SIGKILL を送る前に、各スレッドの待ち先（`/proc/<pid>/task/*/wchan`）を記録する（つぎに固まったときに原因を見るため）
- スタックちゃん: 「ラズパイの温度は？」「車の前に何かある？」などに、ダッシュボード（ラズパイの `GET /api/status`、`--car-url`）の今の値で答える。`stackchan_bridge` の `car_status()` が走行モード・LiDAR の前の距離・障害物・ラズパイの CPU/温度/メモリ/電源・Jetson の CPU/GPU/温度/メモリなどを短い日本語の文にする。ローカルのときは、聞き取りに「ラズパイ」「車」「LiDAR」などが入っていたら Ollama の system に足し、ネットのときは MCP の道具 `self.car.status` を XiaoZhi に見せて呼ばれたら返す。読むだけで、走行・停止の API は使わない
- `lidar_watchdog_node`: USB をつなぎ直しても `/scan` が戻らなければ、4 回目から 2 回、USB の電気（VBUS）を 3 秒切って入れ直し（`systemd/ai-car-usb-power-cycle.sh` → `/usr/local/sbin/ai-car-usb-power-cycle`、uhubctl で xHCI の 4 つのハブを全部切る。ラズパイ 5 の USB の電気はひとまとめなので、ゲームパッドも数秒切れる）、7 回目でラズパイを再起動する（`sudo -n systemctl reboot`）。再起動は、この起動で `/scan` が一度でも来ていて、起動から 30 分（`reboot_min_uptime`）たっているときだけ。2026-10-08 07:08 に CP2102 が固まり（`failed set request 0x12 status: -110`）、USBDEVFS_RESET をくり返しても、ダッシュボードから再起動する 17:53 まで約 10 時間 45 分 `/scan` が来なかった（そのあいだ電圧低下はなく、ラズパイは CPU 約 85 % 空き）。sudoers は `systemd/ai-car-usb-power.sudoers`（`install_service.sh` で uhubctl と一緒に入れる）
- スタックちゃん: 呼びかけ待ちのあいだ、`stackchan_bridge` が 5〜10 秒ごとに首を動かす（純正の待ち受けの首ふり `IdleMotionModifier` の 4 種類をまねて MCP `self.robot.set_head_angles`）。呼びかけのためにスタックちゃんはいつも聞いている（listening）ので、純正の首ふり（待ち受け idle のときだけ動く）が止まっていた。動かしてから 1.2 秒は、モーターの音を声とまちがえないよう新しい声の区切りを始めない。居眠り中・会話中・撮影中は動かさない
- スタックちゃん: whisper に毎回 `no_context=true` を送る。前の聞き取りを手がかりにするので、一度まちがえると、どの声も「(スタックちゃん)」「チャンネル登録をお願いします」にしてしまっていた（起動し直して 4 分でまたなった）。whisper の見回りは「今日の天気はどうですか」も試し、呼びかけが出たら・かっこだけになったら起動し直す
- スタックちゃん: `stackchan_bridge` が 5 分ごとに Kokoro の「スタックちゃん」を whisper-server に聞き取らせ、呼びかけが出なければ whisper-server を止める（`Restart=on-failure` で約 15 秒で起動し直る）。06:06〜06:43 に whisper-server が、どの声も「(字幕を押して)」「チャンネル登録をお願いします」にして、呼んでも居眠りのままだった（起動し直すと同じ録音が「スタックちゃん」と聞き取れた）
- 3D: Camera Module 3 Wide の板（`cam_mount.stl`）の裏に M2 ナットの六角のくぼみ（二面幅 4.4 mm、深さ 1.8 mm）を 4 か所開け、ふた（上の 2 本）と箱（下の 2 本）の前の面にナットとネジの先の逃げ穴（Ø6.5、深さ 4 mm、`wcam_back_relief()`）を開ける。カメラのネジの先・ナットが板の裏から出ると、ふたを組み上げられなかったため。M2 x 10 mm とナットでも、ふた・箱と重ならない。システム構成（architecture.yaml）のカメラの板・カバーの窓・ネジ・組み立てを 2 眼カメラから Camera Module 3 Wide に直す
- スタックちゃんの居眠りと画面の明るさ: `stackchan_bridge` が「じゃあ、またね。」から 30 秒（`--doze-seconds`、0 で使わない）たつと居眠りの顔（`llm` の `emotion` `sleepy`）にして首をホーム（正面・水平）にもどし、呼ばれたらふつうの顔にもどす。見守りの映像の明るさ（1 分の中央値）で、60 秒ごとに画面の明るさ（MCP `self.screen.set_brightness`）を 10・35・75 の 3 段に変える（夜の暗い部屋で明るすぎないように）。ファームウェアの書き換えはいらない。`/status` の `dozing`・`light`・`screen`
- スタックちゃんの呼びかけを、ネットのときにも使い、つながったときから「呼びかけ待ち」にする。「スタックちゃん」と呼ぶと会話モード、最後に話してから 30 秒（`--awake-seconds`）だまると「じゃあ、またね。」と言って呼びかけ待ちにもどる。ネットのときは、呼びかけ待ちのあいだ声を XiaoZhi へ送らず、呼ばれた声を Opus にしなおして送ってから流す。XiaoZhi の聞き取り・話し終わりで会話モードをのばし、話している最中（歌など）は終わらせない。60 秒ごとの ping はネットのときも送る
- スタックちゃん: 会話が切れて（ランプが消えて）いると「スタックちゃん」と呼んでも聞こえないので、ファームウェアに `xiaozhi-auto-reopen.patch` を足し、会話が切れたら自分でつなぎ直す（3 秒後、失敗したら 6・12…最大 60 秒ごと、エラーの音なし）。画面をさわって止めたときはつなぎ直さない。AI Agent を開いたときも 2 秒後に自分でつなぐ。実機では 04:39 にネットのときの通信が切れて、ランプが消えたままになっていた
- スタックちゃんの呼びかけ（ローカルのとき）: `stackchan_bridge` が、画面をさわってから・最後に話してから 30 秒（`--awake-seconds`）たつと「呼びかけ待ち」（`/status` の `state` が `waiting`）にして、whisper の聞き取りに「スタックちゃん」（`--wake-words`、空で使わない）が入っているときだけ返事をする。名前だけなら「はい、なあに？」。スタックちゃんの 120 秒の時間切れで会話が切れないように 60 秒ごとに `{"type": "ping"}` を送る。ファームウェアの「Hi, Stack Chan」（WakeNet、英語の読み上げ声の見本）は日本語の発音で 30 秒に 0 回しか反応しなかったため。ファームウェアの書き換えはいらない。ダッシュボードのスタックちゃんのカードに「呼びかけ待ち」と、話しかける言葉に「スタックちゃん」を足す
- スタックちゃんの見守りとあいさつ: `stackchan_bridge` が 2 秒に 1 枚（`--watch-interval`、0 で止める）映像をもらって face_id で顔を見て、登録した人に「○○さん、こんにちは！」（朝は おはよう、17 時からは こんばんは）とあいさつする。同じ人は 30 分に 1 回。会話・撮影・切り替えの最中と、スタックちゃんがつながっていないときはあいさつしない。ファームウェアの書き換えはいらない（映像の送り係の問い合わせに「1」を返すだけ）。`/status` の `watch_on`・`watch`（`faces`・`names`・`error`）・`greet`。「撮影するよ」で数えるときの首を水平から 30 度上へ（`--shot-pitch`、MCP `self.robot.set_head_angles`）。ダッシュボードのスタックちゃんのカードは、IP アドレス・ネット / ローカル・聞き取り・返事・顔の登録（カメラの映像）だけにする（顔の絵・時刻・かかった時間・ファームウェア・会話の数・仕組みを消す）。名前の欄は写真がまだないときも出し、ボタンだけ押せなくする。顔の見分けはあいさつと表示だけに使い、鍵・走行・安全停止には使わない
- スタックちゃん: 「撮影するよ」「写真を撮って」と言うと、正面を向いて 5 秒数えて撮る。ファームウェアに `stackchan-countdown-shot.patch`（MCP `self.camera.countdown_photo`）を足し、数えている間は画面にカメラの映像と右上に 5〜1 の数字を出す（1 秒ごとにピッ）。数えるのは映像の送り係の task で、会話の動きは止めない。写真（320×240、品質 80）は bridge の `/camera/shot` に届き、Jetson の face_id で顔を見て「撮れたよ。ダッシュボードで名前を登録してね。」などと話す。ダッシュボードのカードの写真の下に、顔の様子と「名前」「名前を登録」（`POST /api/stackchan/enroll?name=` → bridge `POST /enroll` → face_id `/api/face/enroll`）を出す。ネットのときも同じ（撮っている間は XiaoZhi の声を流さない）。顔の見分けはあいさつ・表示だけに使う
- ダッシュボード: スタックちゃんのカードを、2 眼カメラで代わりに見る形（Jetson の face_id）から、本物のスタックちゃんの会話の様子に変える。Jetson の `stackchan_bridge` に `GET /status`（8003）を足し、`GET /api/stackchan/status`（API トークン）で 2 秒ごとに取って、今の様子（聞いている・考えている・話している・待ち受け）の顔、最後の会話（聞き取り・返事・かかった時間）、IP アドレス・ファームウェアの版・会話の数を出す。2 眼カメラを外したので `GET /api/stackchan/face`・`/api/stackchan/frame.jpg` と `face_id_url` は消す（行き先は `stackchan_bridge_url`）。カードに「カメラ（スタックちゃんの目）」を足す: 「写真を撮る」（`POST /api/stackchan/photo`）で、bridge が MCP の `self.camera.take_photo` を呼び、スタックちゃんが 320×240 の JPEG を bridge の `/vision` へ送る（ファームウェアはそのまま、実機で約 0.6 秒）。写真は `GET /api/stackchan/photo.jpg` で出し、Jetson にはいちばん新しい 1 枚だけを置く（保存しない）。さらに、スタックちゃんのファームウェアに `stackchan-camera-stream.patch` を足して、ダッシュボードを見ている間だけ映像を送り続ける（`/camera/frame`、320×240・品質 30・シャッターの音なし、会話とは別）。ダッシュボードは `GET /api/stackchan/frame.jpg` を 0.25 秒ごとに取って、写真の欄に映像と 1 秒あたりの枚数を出す（パッチなしのときは「写真を撮る」のまま）
- Jetson: スタックちゃん（純正ファームウェア 1.5.1 の AI Agent）を家の会話の AI につなぐ `jetson/stackchan_bridge`（`jetson-stackchan.service`）。XiaoZhi の OTA（HTTP 8003、WebSocket の行き先だけ返す）と WebSocket（8000）をまねて、声（Opus 16 kHz）→ whisper-server → Ollama qwen2.5:3b → Kokoro jf_alpha → Opus 24 kHz で返す。ファームウェアは公式のソースに `CONFIG_OTA_URL` を Jetson にする設定と、自動更新をやめるパッチだけを足す。実機で話し終わってから声が出るまで 約 1.6〜2.8 秒。返事の声はいちばん大きい所を -1 dB にそろえる（Kokoro のままだと -7 dB で小さかった）。走行・安全には使わない
- `stereo_camera_node`: 2 眼カメラの MJPG をそのまま受け取り（`CAP_PROP_CONVERT_RGB` 0）、`decode_reduce`（既定 1、dashboard.yaml は 2）分の 1 の大きさで展開する。映像は片目 640×360（前は 960×540）。`pair_scale` は元の大きさに対する割合のまま（片目 320×180）、キャリブレーションの撮影だけ元の大きさで展開する。電池（3 A）に切り替えた後、映像と物体検出が動くと Pi の電力が約 4.0 W・5V が 4.73 V まで下がり、電圧低下が出ていた（取り込みを止めると約 2.7 W・4.92 V で 0 回、距離の計算だけ止めても変わらず）。1 枚の処理は 約 25 → 約 8 ms、実機で Pi の CPU 45〜48 → 33〜34 %、電力 約 4.0 → 約 3.4 W、電圧低下は 50 秒に 0〜3 回 → 3 分に 1 回
- `lidar_watchdog_node`: 起動し直しても `/scan` が 2 回続けて戻らなければ、rplidar を止めた後に LiDAR の USB（CP2102、10c4:ea60）をつなぎ直す（`USBDEVFS_RESET`、`usb_reset_after`）。ラズパイの電池の電圧が下がった後、CP2102 が返事をしなくなり（`cp210x ttyUSB0: failed set request 0x12 status: -110`）、起動し直しを 33 分で 81 回しても戻らず、ラズパイの再起動でしか直らなかったため。書き込み権限は `systemd/99-ai-car-lidar-usb.rules`（`install_service.sh` で入れる）
- ダッシュボード: ラズパイの電池の電圧が下がったら、いちばん上に出す（今下がっている: 赤、起動後に下がった: 橙で回数と最後の時刻）。`system_monitor_node` は `hwmon rpi_volt` の `in0_lcrit_alarm` と `get_throttled` を 1 秒ごとに見て、`power.under_voltage`（`now` / `count` / `last`）を出す
- Jetson: 前の起動の記録をのこす設定（journald persistent）と、メモリ・温度・ファン・止まっているサービスを 1 分ごとに 1 行記録する `jetson-health.timer`（`jetson/health_log`）。放っておくと止まる原因を調べるため
- ダッシュボードの AI HAT+ の負荷率のバーと数字も、ほかの負荷率と同じ 5 色で色分けする（25 % 未満 青 / 50 % 未満 緑 / 70 % 未満 黄 / 90 % 未満 橙 / それ以上 赤）
- ダッシュボードのラズパイの CPU 全体、Jetson の CPU・GPU の負荷率のバーと数字も、コアのバーと同じ 5 色で色分けする（25 % 未満 青 / 50 % 未満 緑 / 70 % 未満 黄 / 90 % 未満 橙 / それ以上 赤）
- ダッシュボードの CPU のコアごとのバー（C0〜C3）と数字を、負荷率で色分けする（25 % 未満 青 / 50 % 未満 緑 / 70 % 未満 黄 / 90 % 未満 橙 / それ以上 赤、色は温度バーと同じ）
- 2 眼の距離の計算を軽くする: `stereo_camera_node` の `pair_scale` を 0.5 → 0.25（片目 640×360 → 320×180）、`stereo_depth_node` の視差を 128 → 64 px（近いほうは同じ約 0.10 m から）、`block_size` 5 → 3、`speckle_window` 100 → 25、`min_points` 40 → 10（同じ広さ）。つながりの穴うめとマスの点の間隔は画像の幅に合わせる。起動の約 5 分後に Pi の CPU の空きが約 6 % になり、SGBM が 1 回 約 300 ms・CPU コア約 1.4 個ぶんだった。320×180 では 1 回 約 25 ms、いちばん近い物の距離はほぼ同じ（1.52〜1.56 m）
- Jetson: Yahboom のケースの横の OLED（SSD1306 128×32、I2C 7 番 0x3C）に、大きな文字の 2 行で CPU・GPU の負荷率と温度 → メモリ・SSD → IP アドレスを 3 秒ごとに切り替えて出す `jetson/oled_panel`（`jetson-oled.service`）。ケースの RGB の光（0x0E）は、AI の負荷（GPU の負荷率の 5 秒平均）で呼吸の色と速さを変える（10 % より下 青・40 % より下 緑・70 % より下 黄・それ以上 赤）。CPU が 70 °C 以上でも赤。JetPack をそのまま入れ直したので、Yahboom のイメージの OLED のプログラムがなく、何も出ていなかった
- `lidar_watchdog_node`: `/scan` が 3 秒来ないと `rplidar_composition` に SIGTERM（3 秒で終わらなければ SIGKILL）を送り、launch の respawn（5 秒後）で起動し直させる。起動直後と起動し直した後は 15 秒待つ。LiDAR の USB（CP2102）が起動の約 1 分後に一度切れて ttyUSB0 → ttyUSB1 でつながり直したとき、rplidar は古いポートを握ったまま `/scan` を出さず、CPU を約 66 % 使い続けていた（`use_lidar` で一緒に起動）
- 2 眼の低い障害物で走る速さを変える: dashboard.yaml の `stereo_guard` を true にする。LiDAR（床から約 17.5 cm の線）に写らない低い物が 2 眼で 0.8 m 以内なら減速、0.45 m 以内なら停止。まちがって止まらないように、0.6 m より近い所の「いちばん近い物」（`nearest`）は、`objects` に残ったまとまり（40 点以上・横幅 2 cm 以上）から選ぶ（窓わくの細い線を 0.19 m の物とまちがえたことがある）
- ダッシュボードの LiDAR の図: カメラで見つけた物の名前・距離の吹き出しを消して点だけにする。2 眼の物（`/obstacle_status.stereo.objects`、なければいちばん近い 1 個）も白ふちの点で描く。色は距離（LiDAR の点と同じ危険・停止・減速・安全の距離帯）、点の直径は横幅の 2 倍（小さい物も見えるように）。`perception_node` は 2 眼の物ごとに横の位置 `lateral` と横幅 `width` も出す
- 2 眼の距離: 視差の幅 `num_disparities` を 64 → 96 px にして、約 0.21 m → 約 0.14 m まで近くを測れるようにする（床の約 0.15 m に置いた高さ約 5 cm の薬のびんが、64 px ではまちがった遠い距離になっていた）。左はしの 96 px は測れない。いちばん近い物の上下の向き（`depression_min_deg`・`depression_max_deg`）も出し、`perception_node` が前方カメラの映像の上の枠（`stereo.box`）にして、ダッシュボードの映像に「2眼 0.15 m 低い物」の枠を出す。前からの床の色の行は「低い障害物（床の色）」と名前を変える
- `perception_node` が 2 眼の距離（`/stereo/depth_status`）のいちばん近い物を、同じ方位の LiDAR の距離と比べる。LiDAR がそれより `stereo_low_margin` 0.15 m 以上遠い（または無い）と「低い障害物」とし、0.8 m で減速・0.45 m で停止と判定して `/obstacle_status` の `stereo` に出す。`stereo_guard: true` のときだけ `level`・`speed_scale` に反映する（既定は `false` で表示のみ）。`stereo_depth_node` は方位（`bearing_min_deg`・`bearing_max_deg`）も出す。ダッシュボードの「2眼の距離」の行に判定を出す
- 2 眼カメラで距離を出す `stereo_depth_node`（表示だけ）。`stereo_calib.yaml` で左右を平行にそろえ、SGBM で距離にして、通り道の中で床より 4 cm 以上高い物のいちばん近い距離を `/stereo/depth_status` に出す。`stereo_camera_node` は受けるノードがいるときだけ、左右を 640×360 の白黒にして `/stereo/pair_gray` に 3 Hz で出す（今の `/camera/image_raw/compressed` はそのまま）。ダッシュボードのカメラカードに「2眼の距離」の行と、映像を距離の色に切り替える「距離の画像」ボタン（`GET /api/camera/depth_stream`）を追加。launch に `use_stereo_depth`（既定 true）。走る・止まるの判断には使わない

### Changed
- Jetson `power_saving/install.sh`: SSD の APST・HMB を切る設定（`nvme_core.default_ps_max_latency_us=0`・`nvme.max_host_mem_size_mb=0`）を入れず、前に入れた分を extlinux.conf から消す。10/9、HMB を切っても起動から 43 分・17 分で SSD が返事をしなくなり、どちらも効かなかったため。Wi-Fi の省電力を切るのはそのまま
- ダッシュボード: カメラ映像の枠と距離の文字の色を、LiDAR の図の点と同じ距離の色（危険 赤 / 停止 橙 / 減速 黄 / 安全 水色、`scanBands`）にそろえる。1 眼・2 眼の低い物の枠（前は橙・灰色）と YOLO の枠（前は赤・緑）、LiDAR の図の YOLO の点も同じ。
- Jetson `power_saving/install.sh`: SSD に Jetson のメモリを貸す HMB も切る（`nvme.max_host_mem_size_mb=0`）。10/9、APST を切っても、SSD を差し直しても、SSD が起動から約 52・60 分で返事をしなくなった（ramoops に `I/O timeout` → `reset controller` → `CSTS=0x1`）ため、次の手として試す。
- プロジェクト説明「システム構成」の図: 3 台の箱の高さを、中の文字に合わせて伸ばす（Jetson の文字が箱の下からはみ出していた）。長い仕様の行は「 / 」で 2 行に分ける。スタックちゃんの「カメラ（GC0308）: …」が YAML で辞書になって「[object Object]」と出ていたのを直し、⑧ の説明が「Hi, StackChan」の「,」で切れていたのを今の呼び方（「スタックちゃん」）に直す
- ダッシュボードの手動運転のカードの API トークンの欄に「APIキー」と出し、ふだんは読むだけにする。「変更」→ 確認 → 入力 →「保存」（または Enter）で保存する（うっかり書き換えないように）
- ダッシュボードのスタックちゃんのカードの状態を「未接続」「接続中（呼び掛け待ち）」「接続中（会話モード）」「おやすみ中」の 4 つにする（`/status` の `connected`・`state`・`dozing`）。`stackchan_bridge` はつながったときに `dozing` をもどす
- ダッシュボード: Jetson カードの「更新・システム」で、セキュリティ更新・再起動・更新するの 3 行を IP アドレスの下へ移し、ラズパイのカードと同じ並びにする
- `stackchan_bridge`: ネットのとき、XiaoZhi の会話は「スタックちゃん」と呼ばれたときに開き、「じゃあ、またね。」で閉じる。呼びかけ待ちのあいだ開いたままだと、XiaoZhi が約 65 秒ごとに「お疲れさん！…じゃあな！」と言って切り、スタックちゃんがつなぎ直す、をくり返していた。XiaoZhi が切っても、スタックちゃんとの会話は切らない
- スタックちゃん: 撮影の言葉を「撮影して」にそろえる（ダッシュボードの案内・説明・コメント。スタックちゃんの返事は「撮影します。こっちを向いてね。」）。聞き分けは今までどおり「撮影」を含めば撮る
- ダッシュボード: スタックちゃんのカードの「聞き取り」を「聞取」にし、「聞取」「返事」の文字を項目名のすぐ右から左寄せで横いっぱいに出す（項目名の幅を 3 文字ぶんにして、長い文でも縦にのびにくくする）
- ダッシュボード: スタックちゃんのカードの「名前を登録」ボタンを「登録」にして、写真の時刻・顔の結果の 2 行の右に移す（名前の欄はその下）
- ダッシュボード: スタックちゃんのカードの「聞き取り」「返事」を、カードのいちばん下（横いっぱい）に移す
- ダッシュボード: スタックちゃんのカードから「映像を撮る」「写真を撮る」のボタンを消す。写真は「撮影して」と言って撮ったものだけを出す（`POST /api/stackchan/photo`・`/api/stackchan/stream` は残す）。撮影の首を 15 度から 30 度上へ（`--shot-pitch`）、数えているあいだ 1 秒ごとに送り直す
- ダッシュボード: いちばん上の電圧の警告を「ラズパイの 5V が足りない（電源の力不足）」にする（前は「電池の電圧」「電池の残りを見て」で、電池の残りと取りちがえやすかった）。直近 10 分の回数を出し、10 分出ていなければ橙をやめて灰色にする（`power.under_voltage.recent_10min`）。CPU カードの「PD対応（5A）」（設定 `usb_max_current_enable` を見ていただけ）を「電源の電流上限 [A]」にし、device tree の `chosen/power/max_current` と PD のやりとりの有無を出す（`power.supply`、5 A 未満は橙）
- 2 眼の低い物（0.6 m より近い `objects`）: 時々出るまちがいの物を 2 種類除く。(1) 右の目からは手前の物にかくれて見えない所（手前の物の視差 d の左 d 画素くらい）の、それより奥の点（`occlusion_shadow`）。のりの棒（0.18 m）の左のカーテンのふちが 0.33 m の物になっていた（20 回中 18 回）。(2) 左の目の明るさの変わり方（Sobel の |横|+|縦| の平均）が `near_objects_min_texture` 40 より小さいまとまり。もようのない床が 0.14 m の物になっていた（20 回中 9 回、値は 14〜22。のりの棒・入れ物は 110〜150）。0.6 m より近い所の `nearest` は今までどおり `objects` から選ぶので、まちがいで止まることも減る。計算は 1 回 約 4〜5 ms ふえる
- ダッシュボードのカメラ映像の枠の文字: 2 眼の枠は「低い物」「（2眼）」を消して距離の数字だけ（例 `0.18`）にする。物の枠も距離の「m」と出し方（「（2眼）」「（LiDAR）」）を消す（例 `person 1.20`）
- ダッシュボード: データが古い・届かない（未接続・途絶）ときは、全部のカードの値を「-」にする。LiDAR（`/scan`）・IMU・`/obstacle_status` は 2 秒、`/system_status` は 3 秒より古いと「-」（AI HAT+ の fps・TOPS・負荷率、物の枠も消す）。カメラは映像なしのとき解像度・fps・最終受信を「-」。SLAM は途絶中の位置と地図を出さない。スタックちゃんは画像が古いとカメラの画像を消す。ラズパイから 3 秒届かないときは、ラズパイのカードだけでなく全部のカードを「-」にし、映像も止める
- `drive_mode_node` の最終段ガード（`obstacle_guard`）: 障害物の stop 判定中だけでなく、LiDAR データなし（`level: unknown`）と `/obstacle_status` の途絶（`obstacle_timeout` 2 秒）のあいだも、手動・自動とも前進を 0 にする（後退と旋回はできる）。これまでは LiDAR が止まっていても手動では前に進めた
- ダッシュボードの LiDAR の図: `/scan` が 2 秒より古いときは点を描かない。LiDAR が止まった後も、最後の点（車の前 0.24 m の赤い点）が残って出ていた
- AI HAT+ の負荷率: 1 回の推論時間は CPU の混み具合で 30〜100 ms とばらつき、最新の 1 回で計算していたので 32〜110 % と大きく動いていた。最近 30 回の中央値で計算し、100 % で止める（`throughput.max_fps` / `max_tops` / `utilization` も中央値から）
- ダッシュボード: 「CPU使用率」「温度・使用率」「CPU 使用」「GPU 使用」を「負荷率」にそろえる
- 2 眼の低い物: 0.6 m より近い物は、画像の上でつながりごとに分けて全部（近い順に 5 個まで）映像に枠を出す（`/stereo/depth_status` の `objects`、`/obstacle_status` の `stereo.objects`）。横幅 2 cm より細いまとまり（窓わくの細い線を 0.19 m とまちがえた）は出さない。今までは、いちばん近い 1 個だけだった。減速・停止の判定（表示だけ）は、今までどおりいちばん近い物で決める
- 2 眼の低い物: 床からの高さの決まりを 4 → 2 cm、視差を 96 → 128 px にする。0.23 m 先の高さ約 3.4 cm の入れ物が床あつかいになり、0.12 m ののりの棒は近すぎて（96 px は約 0.14 m から）測れず、奥のカーテン 0.97 m を出していた。128 px で約 0.10 m から測れるが、左はしの測れない所は約 44° → 約 42° より左に広がり、計算は約 1.4 倍
- 映像の 2 眼の枠の文字を、物の枠と同じ「名前 距離 m（出し方）」の順と大きさ（32 px）にする: 「2眼 0.15 m 低い物」→「低い物 0.15 m（2眼）」（LiDAR にも見える物は「物 1.57 m（2眼）」）
- 物の枠（AI HAT+ の YOLO・Jetson）の距離: 2 眼で測れる所は 2 眼の距離、測れない所（左はし約 44° より左など）は LiDAR の距離にする（`distance_source` が `stereo` / `lidar`、画面に「（2眼）」「（LiDAR）」）。これまでは枠の方向の LiDAR の距離だけで、床から 17.5 cm の線が高い所のテレビ（約 1.5 m）に当たらず、手前の左の物の 0.43 m を出していた。`stereo_depth_node` が点を平行化する前の左目の画像に戻して、32×18 のマスごとの前方の距離（中央値、4 m まで）を `/stereo/depth_grid` に出す

### Removed
- カメラの床の色で低い障害物を見つける `floor_obstacle_node` を消した（`/floor_obstacle_status`・launch の `use_floor`・`perception_node` の `floor_*` と `/obstacle_status` の `floor`・ダッシュボードの「低い障害物（床の色）」の行と映像の足元の線）。窓の光が床に映って白く光るので、覚える床の色の幅が広くなり（明るさ ±59・黄色み ±15）、床の約 0.14 m に置いた白い薬のびんの胴を床とまちがえて、青いふたのふちを足元として 0.22 m と出していた。低い障害物は 2 眼の判定（`stereo`、表示のみ）だけにする

### Fixed
- 3D: バッテリー箱（`box.stl`）の開口側の後ろのボスの上の部分の下に、45° の補強があった（上の 5 mm より下には作らない）。45° の部分をなくし、上の 5 mm の中だけで、上から見て三角の板にして、壁の外側に 20 mm 沿わせた（壁と接する面は約 120 mm²）。柱の部分は壁の端から約 6.5 mm 空中に出るので、そこだけスライサーでサポートを付ける
- 3D: バッテリー箱（`box.stl`）の開口側の後ろのボスに、バッテリーに差す L 字の USB プラグが当たった。上下 5 mm だけ残して真ん中を抜き、上の部分は後ろの壁の端と外側（長さ 15 mm・厚さ 2 mm の板）につないで強くした。下は 45° で壁へつなぎ、サポートなしで印刷できる
- ダッシュボード: 画面の右に 1 列分の余白が残っていた（2 段目はラズパイ・Jetson の 3 列、3 段目はスタックちゃん・AI HAT+ の 3 列）。AI HAT+・IMU・落下防止センサーを 2 段目の右はしへ、スタックちゃんを SLAM の左へ移して、どの段も 4 列を使うようにした。SLAM の地図は幅 640 px までにして、スタックちゃんと高さをそろえる
- 3D: 2 眼カメラの板（`cam_mount.stl`）の四隅の M2 の下穴を Ø1.7 から Ø2.5 にした（Ø1.7 では印刷すると約 0.5 mm の細い穴になった）
- ダッシュボード: ラズパイが落ちても、各カードのタイトルの印が「接続中」のまま残っていた。3 秒データが届かないと、カメラ・LiDAR・ラズパイ・AI HAT+・IMU・落下防止センサー・スタックちゃんを「未接続」、Jetson を「不明」にし、ラズパイのカードの値（温度・CPU・電源・IP など）を「-」にして、WebSocket を張り直す（電源が急に切れると close が来ないことがあるため）。ポーリングのときも、戻ったら接続の表示を戻す
- ダッシュボードの IP アドレスで「（Wi-Fi）」が「Wi-」と「Fi）」の 2 行に分かれることがあったので、アドレスと名前の間だけで折り返すようにした
- ダッシュボードの「Raspberry Pi 5 — CPU」と AI HAT+ の温度・状態が「-」のままだった。「システム構成」タブの図を描く関数を同じ名前 `renderSystem` で足したので、テレメトリー表示の `renderSystem` が上書きされていた。図のほうを `renderSystemDiagram` に改名した

### Added
- ダッシュボードに「M5 スタックちゃん（CoreS3）」カード。本体が届くまでは AI-CAR の 2 眼カメラ（左目）を代わりに使い、Jetson の face_id の結果（だれか・近さ・登録している人・1 回の時間）、顔の枠を重ねたカメラの画像、画面の顔（笑顔・普通・眠る。目が顔のほうを向く）、首の向きの目安を出す。`GET /api/stackchan/face`・`/api/stackchan/frame.jpg`（API トークン）が Jetson の 8090 へ取りに行く（表示だけ）
- ダッシュボードの Jetson カードの「声→文字」「文字→声」に、使っている仕組みの名前を出す（例: `whisper.cpp small（GPU） / 稼働中`、`Kokoro TTS 1.0.0 / 稼働中`）。`jetson_status.py` が `whisper-server.service` の `-m` と Kokoro の `/openapi.json` から `stt_engine`・`tts_engine` を作って送る（60 秒ごとに見直す）
- ダッシュボードのラズパイと Jetson のカードに「電源を切る」ボタン（確認の画面あり、API トークンが必要）。ラズパイは `POST /api/system/poweroff`（走行中・自動運転中は断り、止めてから 10 秒後に `systemctl poweroff`。そのあいだに押した Jetson の再起動・電源を切ることも伝えてから）、Jetson は `POST /api/jetson/poweroff`（次の状態の返事の `poweroff` で `jetson_status.py` が `systemctl poweroff`）。`ai-car-reboot.sudoers`・`jetson-reboot.sudoers` に `systemctl poweroff` を足した。ラズパイの sudo の確かめは `sudo -n -l` の NOPASSWD の行で見るようにした。入れ直すのは本体の電源ボタンか電源のつなぎ直し

### Changed
- ダッシュボードのラズパイと Jetson のカードから「最後の自動更新」の行を消した（値は今も送っている）
- カメラの物の検出: 間隔を前の検出の「始まり」から数え、同じコマは 2 回検出しない（`inference_rate: 15` なのに、検出の時間と待ち時間が足されて実際は 1 秒に約 8 回だった）
- ダッシュボードの AI HAT+ のカード: PCIe の番地を消し、「負荷率」を横のバーで出す（1 秒のうち推論している時間の割合 = fps × 1 回の推論時間。Hailo-8 は NPU の使用率を返さないので推論レートから出す）
- ダッシュボードの LiDAR の図に、上から見た車体を本当の大きさで描く（天板 200 x 154 mm・前後のバンパー・カバー・メカナムホイール 4 つ・LiDAR・2 眼カメラのレンズ。寸法は battery_lidar_mount.scad と ai_car.xacro。車輪の左右の位置は見込み）。点群は車体の上に描く
- ダッシュボードの温度（ラズパイ・AI HAT+・Jetson の CPU/GPU）を、バーと数字の両方で温度ごとに色分けする（45℃ 未満 青 / 60℃ 未満 緑 / 70℃ 未満 黄 / 80℃ 未満 橙 / 80℃ 以上 赤）
- ダッシュボード: 「Raspberry Pi 5 — CPU」と Jetson のカードの 2 行目（タイトルの下）に OS の名前（`/etc/os-release` の `PRETTY_NAME`）を出す。マウスを当てると、ラズパイはカーネル、Jetson は L4T の版が出る。`system_monitor_node` が `/system_status` に `os`・`kernel` を足した（Jetson は前から `os` を送っている）
- ダッシュボード: 「ラズパイを更新」「Jetson を更新」のあいだ、「更新中」の横に進み具合（例: 「更新中 45 %」）を出す。更新スクリプトが `apt-get install -o APT::Status-Fd=3` の `dlstatus`（ダウンロード、0〜30 %）と `pmstatus`（インストール、30〜100 %）を `/run/ai-car-upgrade.progress`・`/run/jetson-upgrade.progress` に書き、`system_monitor_node`・`jetson_status.py` が `upgrade_percent`・`upgrade_phase` として送る。`apt-get update` のあいだは「更新の準備中」。いまダウンロードかインストールかは、印にマウスを当てると出る
- ダッシュボード: Jetson カードと同じように、カメラ・LiDAR・Raspberry Pi 5 — CPU・AI HAT+・IMU・落下防止センサーのカードのタイトルの横にも、つながっているかの印（接続中 / 途絶 / 未受信。カメラは映像なし、AI HAT+ は未検出・ドライバ未導入・無効、落下防止センサーは未配線・未接続も）を出す。LiDAR・IMU は 2 秒、`/system_status` は 3 秒届かないと途絶（`renderLinks`）
- 3D 部品（ふた `lid.stl`）: 2 眼カメラの板を留めるふたの前端の柱 2 本の M3 の穴を貫通にした。板の上の M2 のネジ 2 本の後ろに、M2 ナットの六角のくぼみ（二面幅 4.4 mm、深さ 2.5 mm）とネジの先の Ø2.4 の穴を開けた。IMU の台を LiDAR の後ろの柱 2 本の間（`imu_c` [90, 145] → [65, 122.3]）へ移して -90° 回し、ピンヘッダーの開いた側を Pi 側（後ろ）に向けた。ふたの後ろ端の結束バンドの受け（LiDAR とカメラの USB）は X 69 → 86 mm へずらした
- Jetson カードの「セキュリティ更新」の「全部」の数から、NVIDIA の部品（自動でもボタンでも更新しない、今は 48 個）を除いた
- ラズパイの再起動は、押してから 2 秒後ではなく 10 秒後にした。そのあいだに Jetson の再起動ボタンを押しても受け付け、Jetson に伝えてからラズパイを再起動する。前はラズパイ → Jetson の順に押すと、Jetson に伝わらなかった
- ダッシュボードの「Jetson」カードを、いちばん下から「Raspberry Pi 5 — CPU」の右へ移した（幅 2 列、中は 2 × 2）。ラズパイと Jetson の状態を同時に見られる。AI HAT+・IMU・落下防止センサーは、その右へ
- ラズパイの再起動は、Jetson への再起動の頼みが残っていれば、伝え終わるまで（最長 10 秒）待ってから再起動する。前は 2 秒後に再起動したので、ラズパイと Jetson を続けて押すと Jetson に伝わらなかった
- Jetson の状態を送る間隔を 5 秒から 1 秒にした（`jetson_status.py --interval` の既定）。「未接続」になるまでも 15 秒から 5 秒にした（`JETSON_STATUS_TIMEOUT`）。Jetson で 1 回集めるのに CPU 約 0.011 秒なので、1 秒ごとでも CPU 1 コアの約 1 %
- ダッシュボードの Jetson カードから「電源モード」「ファン」「物体検出」（NanoOWL、止めている）の行を消した。「会話の AI」を「qwen2.5:3b / 稼働中」（読み込み中のモデル / 状態）の順にし、セルが狭いときはモデル名を省略せずに折り返す（`td.v.wrap`）。Jetson から送る値はそのまま
- Jetson の会話の AI（`qwen2.5:3b`）を、いつもメモリに読み込んだままにした（`jetson/ollama/`: `voice.conf` に `OLLAMA_KEEP_ALIVE=-1`、電源を入れたときに読み込む `ollama-preload.service`）。5 分使わないと外れて、ダッシュボードの「会話の AI」にモデル名が出なかった。外れているときの表示は「稼働中 / なし」（短くして、文字が切れないようにした）
- ダッシュボードの Jetson カードの「会話の AI」を「稼働中 / qwen2.5:3b」（状態 / 読み込み中のモデル）の 1 行にし、その下に「GPU / CPU」（GPU と CPU で動く割合、`ollama ps` の PROCESSOR と同じ）と「GPU / 全体」（GPU に載っている量 / モデルの大きさ、GB）を足した。`jetson_status.py` は Ollama の `/api/ps` の `size`・`size_vram` の合計を `llm_size_mb`・`llm_vram_mb` で送る。GPU が 90 % 未満のときは黄色（CPU で動く分だけ返事が遅くなる）。「読み込み中」の行はなくした
- 2 眼カメラを 3D の板（`cam_mount`）に USB 端子を上にして付け替えたので、`stereo_camera_node` の `rotate_180` を true → false にした（ノードの既定も false）

### Added
- 2 眼カメラのキャリブレーションの道具。ダッシュボードのカメラカードの「キャリブレーション」の「撮影」（`POST /api/camera/calib_capture`、API トークンが必要）で、`stereo_camera_node` の `~/capture_calib`（std_srvs/Trigger）が、その時の左右の画像（片目 1280×720）で市松模様（内側の角 9×6）を探し、左右とも見つかれば `~/AI-CAR_ws/calib/stereo/pair_NNN_left.png` / `_right.png` に保存する。`ros2 run ai_car_web stereo_calibrate`（`ai_car_web/stereo_calib.py`）が左右のゆがみ・向きのずれ・レンズの間隔・画角を求めて `stereo_calib.yaml` に書く。印刷用の市松模様（A4、1 マス 24 mm）と手順は `docs/calib/`。距離の計算はまだしない
- ダッシュボードの「Raspberry Pi 5 — CPU」カードに、Jetson と同じ更新の行（「セキュリティ更新」「再起動」「最後の自動更新」）と「ラズパイを更新」ボタンを追加した。`system_monitor_node` が `apt-check` で 1 時間に 1 回（とボタンの更新のあと）数を調べ、`/system_status` の `updates` で送る。ボタンは `POST /api/system/upgrade`（走行中・自動運転中は断る）で `ai-car-upgrade.service`（`systemd/ai-car-upgrade.sh`、ROS 2 も含めて更新、消える部品があるときはやめる）を始める。sudo は `systemd/ai-car-upgrade.sudoers` でこのサービスを始めることだけ許す。自動のセキュリティ更新（unattended-upgrades、Ubuntu の既定、自動の再起動なし）は前から動いている
- ダッシュボードの Jetson カードに「Jetson を更新」ボタンを追加した。押したときだけ、NVIDIA の部品（JetPack）以外を更新する（`jetson/status_reporter/jetson-upgrade.sh`・`jetson-upgrade.service`・`jetson-upgrade.sudoers`）。更新中は「更新中」、終わると「前回は成功 / 失敗」と出る
- ダッシュボードの「Raspberry Pi 5 — CPU」と「Jetson」のカードに、IP アドレス（Tailscale・Wi-Fi など。lo・Docker は出さない）と「再起動」ボタンを付けた。押すと確認の画面が出る。ラズパイは `POST /api/system/reboot`（走行中・自動運転中は 409 で断り、止めてから 2 秒後に `sudo -n systemctl reboot`）、Jetson は `POST /api/jetson/reboot`（次に状態が届いたときの返事に `reboot: true` を入れ、`jetson_status.py` が再起動する）。どちらも API トークンが必要。パスワードなしで `systemctl reboot` だけを許す sudoers（`systemd/ai-car-reboot.sudoers`、`jetson/status_reporter/jetson-reboot.sudoers`）が要る。IP は `system_monitor_node` の `/system_status` の `ips`、`jetson_status.py` の `ips`（30 秒ごとに調べる）
- ダッシュボードに「Jetson Orin Nano Super — AI 担当」カードを追加。Jetson の新しい `jetson/status_reporter/jetson_status.py`（`jetson-status.service`、標準ライブラリだけ）が 5 秒ごとに温度（CPU・GPU）、CPU / GPU の使用率、メモリ・スワップ・ディスク、消費電力（INA3221 の `VDD_IN`）・電源モード・ファン、AI の部品（声→文字 whisper-server・会話の AI Ollama と読み込み中のモデル・文字→声 Kokoro・物体検出 NanoOWL）が動いているか、セキュリティ更新の残り（`apt-check`、1 時間に 1 回）・再起動が必要か・最後の自動更新の時刻を `POST /api/jetson/status`（API トークンが必要）へ送る。`dashboard_node` は最新の 1 件を覚えて `/api/status`・`/ws` の `jetson_host` に出し、15 秒届かないと「未接続」にする。表示だけで、速度や安全の判定には使わない。「システム構成」タブにも「状態」のやりとりを足し、Jetson の説明を今の状態（声の AI が稼働中、NanoOWL は停止中）に直した
- プロジェクト説明に「システム構成」タブを追加。AI-CAR（Raspberry Pi 5）・Jetson Orin Nano Super・M5 スタックちゃん・ブラウザ・家の人のつながりを図にし、やりとり（① カメラの画像 `GET /api/camera/snapshot` ② 物の名前・位置 `POST /api/jetson/detections` は稼働中、③ 声の命令 `POST /api/cmd_vel`・`/api/stop`、④⑤ スタックちゃんと Jetson の声・映像・返事は予定で点線）と機械ごとの役割を表にした。内容は `architecture.yaml` の `system`
- ラズパイ台の Pi 5 を左へ 32 mm 寄せた（`pi_cx` 79 → 47 mm）。カバーの左の壁に電源ボタンを押す穴（18 × 11 mm、Y 22〜40 mm）をあけ、カバーを付けたまま指先か細い棒で押せるようにした。右の USB / LAN の口からカバーの右の壁まで約 29 → 61 mm に広がり、ストレートの USB プラグも入る。穴をよけるため、カバーの後ろのフックを Y 30 → 54 mm、受けを Y 18 / 42 → 42 / 66 mm に移し、通気口も Pi に合わせて左へ移した。`pi_base.stl`・`cover.stl` を作り直した（ボタンの位置は図面に寸法がないので広めに見込み、実物では未確認）
- 3D プリント部品を作り直した（Pi のまわりをすっきりさせ、前方カメラを USB の 2 眼カメラにしたため）。Camera Module 3 の板・ボス・フラットケーブルの通り道と、液晶の台・カバーの液晶の窓をなくした。2 眼カメラ（基板 80 × 17 mm、レンズの間隔 約 60 mm）は、USB 端子を上にして、ふたの前（LiDAR のモーターの下）に立て、左右のレンズの真ん中を LiDAR の回転中心にそろえた。実測（レンズは基板から 26 mm・太さ 18 mm、四隅の M2 の穴の中心はふちから 1.5 mm、裏の部品 2 mm）に合わせ、新しい板（`cam_mount.stl`）の支柱 4 本に前から M2 × 6 mm で留め、板はふたの前端の面に当てて左右の耳をふたの柱に M3 × 8 mm で留める。L 字の USB-C プラグが入るように、基板の上端を LiDAR のモーターの下端から 15 mm 下げた（レンズの中心は天板から 40.4 mm）。レンズの先はカバーより 13.3 mm 前に出るので、カバーの前面にはレンズごとの窓（Ø18 mm + 片側 1.5 mm）を下の端から切り込み、左右の窓の間（基板の中央・USB 端子・チップ）は壁で守る。加速度センサー（GY-BNO055）の台は Pi の右からふたの上・LiDAR のヘッドの下へ移した（台の上端は天板から 72.3 mm、LiDAR の中央の基板の下まで約 10 mm）。カメラの位置に合わせて `camera_offset_x_m` 0.053 → 0.079・`camera_offset_y_m` −0.044 → 0.030・`camera_height_m` 0.128 → 0.112・`corridor_center_y_m` 0.036 → −0.038 と、URDF の `camera_link`・`imu_link` を CAD の値にした（実物ではまだ測っていない）。`lid.stl`・`pi_base.stl`・`cover.stl` を更新、`cam_mount.stl` を追加し、図を更新（`camera_back.png`・`camera_ribbon.png` は消した）。IMU の向きが変わったので、ROS の IMU の軸の補正はまだしていない。カメラは今の付け方のままなので `rotate_180` は true のまま（この板に付け替えたら false にする）
- USB の 2 眼カメラ（ELP 3D USB Camera、32e4:0035）を前方カメラとして使う `stereo_camera_node` を追加。左右横並びの 2560×720 MJPG を V4L2（OpenCV）で読み、上下逆さまに付けているので 180° 回し（左右の画像も入れ替わる）、左目を 960×540・JPEG 品質 80 にして、これまでと同じ `/camera/image_raw/compressed` に出す。ダッシュボード・`perception_node`（Hailo-8 YOLO）・`floor_obstacle_node`・Jetson はそのまま使える。`dashboard.launch.py` に `camera_type`（既定 `stereo`、`picam` で Camera Module 3 の `camera_ros` に戻せる）を追加。CPU は 30fps で約 108%、15fps で約 52% だったので 15fps にした（`CAP_PROP_BUFFERSIZE` を 1 にするとカメラが 15fps に落ちるので設定しない）。`camera_hfov_deg` は仮に 120°（`floor_obstacle_node` の縦は 88.6°）。広角でゆがみがあるので、画角・取り付け位置（`camera_offset_*`・`camera_height_m`）は実測して直す必要がある。2 眼カメラをつないだときの電源は、取り込み中 4.94〜5.0V・1.32A（つなぐ前 0.98A）、`get_throttled=0x0`
- LiDAR の図に、カメラの見える範囲（`camera_hfov_deg` 66° の扇形、カメラの取り付け位置から）と、カメラで見つけた物（Jetson は水色、YOLO は緑 / 赤）の位置・名前・距離（「段ボール箱 0.75m」）を重ねて表示。LiDAR の図は車の前がいつも上なので、写真と見比べやすくするため。距離が分からない物は方向だけ点線で表示。`/obstacle_status` に `camera_offset_x_m` / `camera_offset_y_m` を追加
- Jetson Orin Nano Super で AI-CAR のカメラ画像の物の名前を見分ける仕組みを追加（表示のみ、速度は変えない）。Jetson の `jetson/owl_detector/owl_detector.py` が `GET /api/camera/snapshot` の画像を NanoOWL（言葉で物を探す AI、`prompts.json`）にかけ、重なった枠を 1 つにまとめて `POST /api/jetson/detections`（API トークンが必要）へ送る。`dashboard_node` はそれを新しいトピック `/jetson_detections` に流し、`perception_node` が同じ方向の LiDAR の距離を付けて `/obstacle_status` の `jetson` に入れる。ダッシュボードのカメラ映像に水色の枠と「段ボール箱 0.61 m」のような名前・距離、表に「Jetson 検出」を表示。実機の画像（960 × 540）で袋 0.69・段ボール箱 0.62 を検出、1 枚約 35 ms。白い箱は「段ボール箱」（0.50）になり、色の言い分けは苦手
- LiDAR の画面の「前方」を前方カメラの正面に固定。実測（カメラの画面の真ん中のボトルが LiDAR で右 4°・0.47 m）から `scan_angle_offset_deg` を 0° → −1.7° にし、`dashboard_node`・`perception_node`・`autonomy_node` と URDF の `laser` の向き（`laser_yaw_deg`）を同じ値にした。前に入れた「カメラの正面で前方を合わせる」ボタン（`POST /api/lidar/align`、`~/.config/ai_car/lidar_calibration.yaml`）は使わないので消した。LiDAR 点群の表示範囲を自動から 3 m の固定にし、3 m より遠い点は描かない
- カメラと LiDAR の取り付け位置の差の補正を進めた。`perception_node` は LiDAR の点をカメラのレンズの位置（`camera_offset_x_m` 0.053 / `camera_offset_y_m` −0.044）に移し、方位だけでなく距離もカメラから前方への距離で返す（これまでは LiDAR の中心からの距離で、カメラより約 5 cm 遠く出ていた）。床の検出（`floor_obstacle_node`、カメラから前方への距離）と同じ基準になり、「低い障害物」の比較と人・動物の減速・停止の距離がずれない。画像の横位置から方位への変換を、比例（`(0.5 − x) × HFOV`）からピンホールの式（`atan((0.5 − x) × 2 tan(HFOV/2))`）に変え、`floor_obstacle_node` と同じにした（画面の 1/4 の位置で約 1.5° ずれていた）。URDF（`ai_car.xacro`）の `laser` と `camera_link` を仮の位置から CAD の位置に直した（天板の中心から LiDAR は前 43 mm・左 8 mm・床から 175 mm（光の高さは推定）、カメラは前 96 mm・右 36 mm・床から 128 mm）。SLAM の TF に使う
- SLAM（地図と自己位置）のソフトを用意。`slam_toolbox`（online async）を `slam.launch.py` で起動し、`dashboard.launch.py` の `use_slam:=true` でも読み込む（既定 false）。`robot_state_publisher` が URDF から `base_link → laser` の TF を出す。車輪のオドメトリ（`/odom`）がまだ無いので、`odom → base_footprint` は固定の TF（`odom_source:=none`）にして、位置は LiDAR のスキャンどうしの照合だけで出す（`minimum_travel_*` 0）。設定は `config/slam_toolbox.yaml`（5 cm / セル、12 m まで）。ダッシュボードに「地図と自己位置（SLAM）」カードを追加し、`/map` を PNG（`/api/slam/map.png`）にして自己位置（`/pose`）の矢印と表示、「地図を保存」（`/api/slam/save` → `/slam_toolbox/save_map`、`~/AI-CAR_ws/maps` に .pgm / .yaml）。ラズパイに `ros-jazzy-slam-toolbox` を入れた。地図の保存は `nav2_map_server` の `map_saver_cli` を使うので `ros-jazzy-nav2-map-server` も入れた（無いと save_map が result 255 で失敗する）。保存した地図（`maps/`）は git に入れない
- カメラで床の上の低い障害物（LiDAR の光が上を通る物）を見つける `floor_obstacle_node` を追加。カメラの高さ（`camera_height_m` 0.128 m）と向き（`camera_pitch_deg` 0°）から、画面の行ごとの床までの距離を計算する。通り道（車体の中心 ± 0.15 m、1.5 m 先まで）の中を各列の下から上へ見て、床の色（いちばん近い 0.35〜0.45 m の帯から覚える Lab の色）と違う所が 3 行続いた所を足元とし、幅 3 cm 以上・3 コマ中 2 コマで確定して `/floor_obstacle_status` に 5 Hz で出す。`perception_node` は同じ方向の LiDAR の距離がカメラより `floor_low_margin` 0.15 m 以上遠い（または無い）ときに「低い障害物」とし、0.8 m で減速、0.45 m で停止と判定して `/obstacle_status` の `floor` に出す。`floor_guard: true` のときだけ `level`・`speed_scale` に反映する（既定は `false` で表示のみ）。ダッシュボードの障害物の欄に「低い障害物」の行、カメラ映像に足元の線を表示。`use_floor`（既定 true）
- 人・動物（`living_labels`: 人・犬・猫・鳥）をカメラの AI 検出（YOLOv8m）で見つけたら、LiDAR より早めに減速・停止する判定を `perception_node` に追加。カメラの前方（画面の中央半分）に写り、LiDAR の同じ方向の距離が `living_slow_distance` 1.5 m 以内なら減速、`living_stop_distance` 0.6 m 以内なら停止。`/obstacle_status` の `living` に判定を出し、ダッシュボードの障害物の欄に「人・動物」の行を追加。`living_guard: true` のときだけ `level`・`speed_scale` に反映する（実機の準備ができるまでは `false` で表示のみ）
- Raspberry Pi 5 — CPU カードで、コアごとの使用率（C0〜C3）を表の下から、全体の CPU 使用率のバーのすぐ下へ移動
- 3D プリントタブの組み立て図 3 つ（組み立て図・カバー付き・カバー付き・試験台）に、天板の下の車輪・モーター・モーターの台（購入品、印刷しない）を表示。OSOYOO の図面の寸法で参考の形を作った（`hardware/3d/drivetrain/`、`wheels.stl`・`motors.stl`・`holders.stl`、天板と同じ座標）。`architecture.yaml` の `print3d.refs` に置き、組み立て図だけで使う（部品の一覧・ダウンロードには出さない）。組み立て図の凡例は、はみ出すときに折り返す。`setup.py` で `drivetrain/` の STL・SCAD もインストール
- Raspberry Pi 5 — CPU カードのファンの下に、メモリ（使用 / 合計 [GB] と使用率）と Swap 使用率を追加（`/system_status` の `memory` を表示）
- 車体を載せて車輪を浮かせる試験台を追加（`hardware/3d/test_stand/`、`test_stand.stl` 1 個、167.4 × 202 × 88 mm）。カバーとバンパーを付けたまま、天板の 4 隅の下面（25 × 15 mm）を床から 80 mm で受ける（車輪は約 10 mm 浮く）。車体とのすき間は 1 mm（カバーの左右の壁の外側に位置決めの壁、受け面の外側はカバーの壁の下端とバンパーから 1 mm 下げる）。4 隅の柱は厚さ 10 mm の床板でつなぎ、床板は外周の枠 8 mm と斜めの格子のリブ 5 mm の中抜き、柱の内側に三角の補強。3D プリントタブに部品と「組み立て図（カバー付き・試験台）」を追加（`setup.py` で `test_stand/` の STL・画像・SCAD もインストール）。車輪の寸法は仮の値
- 3D プリントタブの「組み立て図（カバー付き）」で、カバーが 20 mm 低く、前後が反転して表示され、カメラの板と LiDAR の柱がカバーを突き抜けて見えていた問題を修正。`cover.stl` は X 軸まわりの 180° 回転で上下を返しているので、立体図の配置に `rotate_x` を追加し、カバーを `rotate_x: 180`・`translate: [0, 205.5, 82.4]`（`cov_oy0 + cov_oy1`、`cov_oz`）で置く
- ふたの前端のカメラの板のネジ穴 4 か所を、M2 のねじ込み穴（深さ 6 mm）から、M2.5 のネジがボスと板を貫通する Ø2.9 の通し穴に変更（`cam_scr_m`）。カメラの前から M2.5 × 12 mm を通し、板の裏でナットで留める。下の 2 か所の裏のナット（Ø5.8）が補強リブに当たらないよう、板の幅を 28 → 32 mm にした（リブは両端のまま外へ 2 mm ずつ）。カバーのカメラの切り欠きも 30 → 34 mm に広がる。`lid.stl`・`cover.stl` と `camera_mount.png` を更新し、板の裏から見た `camera_back.png` を追加
- 上面カバーを 20 mm 高くした（`cov_top` 60 → 80 mm。上面の外側は天板から 82.4 mm、`cover.stl` の高さは 67.9 → 87.9 mm）。Pi の 3 段の上端から上面の裏までは 26 mm、Pi の支柱の長さは 31 mm まで使える。LiDAR のヘッドがカバーの上に出るよう、ふたの LiDAR 取付柱も 28 → 48 mm にした（取付面は天板から 70.4 → 90.4 mm、カバーの上面より 8 mm 上。`lid.stl` を更新）。柱の下の座ぐりが 48 mm の深さになるので、軸が Ø5 より細く長さ 50 mm 以上のドライバーで留める。後ろの斜面は上端が高くなった分だけ急になり、液晶の窓は上に長くなった。バッテリーの残量表示からカバーの上面までは約 47 mm。`cover.stl`・`lid.stl` と `assembly.png`・`side.png`・`wiring.png`・`wiring_front.png`・`cover_assembly.png`・`cover_right.png`・`cover_rear.png`・`battery_display.png` を更新
- 落下防止センサー（VL53L1X ×2、前後バンパー）をソフトの上で組み込んだ（配線はまだで、配線色は未定）。新しい `cliff_node` が前後の床までの距離を測り、段差の判定を `/cliff_status` に 20 Hz で publish する（距離が `cliff_distance_m` 0.15 m を超えるか床が見えない状態が 2 回続くと段差）。初期アドレス 0x29 が BNO055 と重なるので、XSHUT（前 GPIO17 / pin 11、後 GPIO27 / pin 13）を 1 台ずつ上げて 0x30 / 0x31 に変える。`drive_mode_node` は前が段差なら前進、後ろが段差なら後退を止め、自動運転は停止にする（`cliff_guard`）。未配線の間は `cliff_node.wired: false` で I2C / GPIO に触らず「未配線」だけを配信し、走行は止めない。ダッシュボードに「落下防止センサー」カード、`gpio_pins.yaml` に予定のピン（配線色は空欄）、プロジェクト説明にノード・トピック・安全機構を追加。`use_cliff`（既定 true）
- 3D プリントタブの「立体図（回して見る）」で、マウスのホイールを押したままドラッグすると、ブラウザの自動スクロールが始まってページ全体が上下に動いていた。立体図の上ではホイールのクリックで自動スクロールしないようにし、注視点の移動（右ドラッグと同じ）に使う
- 3D プリントタブの「立体図（回して見る）」で、ドラッグで回すときの中心を、押した所の部品の面の点にした（何もない所を押したときは、これまでどおり表示の中心）。これまでは部品全体の箱の中心のまわりに回っていたので、拡大して上下にドラッグすると、見ている所が画面の上下へ大きく動いた。また、大きさを最初の向きで決めて固定し、回すたびに拡大率が変わらないようにした
- 上面カバーの印刷用 STL（`cover.stl`）が、組立図を鏡に写した形になっていた（上面を下にするのに Z 方向の `mirror` を使っていた）ため、印刷すると「AI-CAR」の文字が裏から見た向きになり、充電口・カメラの切り欠き・液晶の窓も左右が逆になっていた。X 軸まわりに 180° 回す形に直した。カバーのフックを天板の前後の端から 30 mm（左右とも Y 30 / 170 mm、以前は 45 / 193 mm）へ移動。右前のフックは充電口の下の細い帯にあり、たわませる長さが取れないので、切れ目のない固定の爪にした（`cov_hook_fixed`）。天板の上面に載る受けは、フックの両隣（前後に 12 mm）と中央に置き直した（右 5 か所、左は液晶の台のベースをよけて 4 か所。以前は左右 3 か所ずつ）。`cover.stl` と `cover_assembly.png`・`cover_right.png`・`cover_rear.png` を更新
- 加速度センサー（GY-BNO055）の台の奥の長辺（Pi 側、-X）の壁の上端に、内側へ 3 mm・厚さ 3 mm の出っ張りを付けた（`imu_lip`・`imu_lip_t`）。これまでは基板を段に載せるだけで、上から押さえるものがなく固定できなかった。出っ張りの下面は基板の上面から 0.3 mm 上。基板は右の開いた側から斜めに入れ、Pi 側の縁を出っ張りの下に差し込んでから段に載せる。`pi_base.stl` と `sensors.png` を更新
- バッテリー箱の開口と反対側（左）の端の壁を、内側へ 2 mm 厚くした（`end_fill`、2.5 → 4.5 mm。外形は変えない）。実物では長手方向に約 2 mm のすき間があり、厚さ 2 mm のプレートを入れるとがたつきが止まったので、その厚さを箱に反映した。確認用のプレート（`bat_shim.stl`）はなくした。バッテリーが 2 mm 開口側へ寄るので、ふたとカバーの残量表示の窓も 2 mm 右へずらした。印刷し直すのは box.stl・lid.stl・cover.stl
- ラズパイ台の Pi 5 の受け 4 か所を、M2.5 の六角支柱（幅 5 mm）を差し込む丸い穴（Ø6.2、深さ 5 mm）に変えた。丸い穴なので、支柱を回して向きを合わせなくても入る。支柱は台の裏から M2.5 × 6 mm のネジで留める（ネジの頭は座ぐりに沈める）。ボスの高さは 6 mm のままで、太さは Ø6 から Ø9.4 にした。Pi の高さは、支柱の長さ `pi_so_l` から計算する（`pi_z`）。`pi_base.stl` と `sensors.png` を更新
- ラズパイ台の左側で、液晶の台のベース（`wing`）と後ろ左の 2 本の腕の間に残っていたすき間（ベースの右の縁の幅 1 mm の貫通したすき間 2 か所と、ベースの前後の角と腕の間の切れ込み 2 か所）をなくした。ベース・2 本の腕・Pi のボスの左の角を `hull()` で厚さ 3 mm の 1 枚の板にまとめた。外形の大きさは変えていない。`pi_base.stl` と `sensors.png`・組み立て図・配線図・`top.png` を更新
- 加速度センサー（GY-BNO055）の台の短い方向（X）を、ピンヘッダーの側で 2.56 mm 短くした（`imu_hdr`）。基板の下のピンヘッダーの列は +X 側の長辺に沿って全長にあり、その幅の分は台（前後の段）に当たって入らなかった。台は基板の Pi 側の縁から 9.44 mm までを受け、ピンヘッダーの列は台の外にはみ出す。`pi_base.stl` と `sensors.png` を更新
- 加速度センサー（GY-BNO055）の台で、溝の上側の押さえ（縁 1 mm）をなくした。基板の上面は縁までチップ抵抗・コンデンサーがあり、実物では押さえに当たって溝に入らなかった。基板は 3 辺の内側の段（`imu_ledge` 1 mm）に下から載せ、壁（基板の上面より 1.5 mm 高い）で横ずれを止める。上から入れて、右の縁をテープかホットボンドで留める。`pi_base.stl` と `sensors.png` を更新
- ラズパイ台の Pi 5 のボスを 2 mm 右（+X）へ移動（`pi_cx` 77 → 79）。Pi の -X 側の短辺と液晶スタンドの右端のすき間が 0.65 mm しかなく、実物では基板と PCIe のフラットケーブルがスタンドに当たって、ボスとスペーサーの位置がずれていた（すき間を 2.65 mm にした）。LAN 端子とのすき間を保つため、IMU の台と下の板も 2 mm 右へ移動（`imu_c` [134, 25.6]、`imu_pad` X 124〜141.5 mm）。`pi_base.stl` と `sensors.png`・組み立て図・配線図・`top.png`・`side.png` を更新
- 落下防止センサー（VL53L1X）の受けの窓を、実物の下面のレンズのカバー（12.2 × 7.4 mm、基板の中心から約 1.9 mm 片寄り、縁は基板の長辺まで）に合わせて変更。これまでの窓（22 × 7.7 mm、長辺の縁 1.5 mm で受ける）ではカバーが縁に当たり、基板が入らなかった。窓は幅 13.4 mm（`tof_win`）で長辺の方向は受けの穴いっぱいに開け、基板は左右の耳（丸穴の部分）で受ける。丸穴の部分の開口はなくした。`bumper.stl` と `bumper_under.png` を更新
- 加速度センサー（GY-BNO055）の台を、液晶の取り付けに干渉しないよう Pi の左側から右側（USB・LAN の側、`imu_c` = [132, 25.6]）へ移動。ピンヘッダーのある長辺をふさいでいた四方の壁をやめ、その長辺（+X）を開けて、残りの 3 辺の溝で基板の縁を上下から押さえる形にした（基板はジャンパー線を差したまま右から差し込む）。台の下に 3 mm の板（`imu_pad`）を足し、LAN 端子・天板の穴のネジ頭・後ろ右のモーターのネジをよける。IMU の配線は Pi の右後ろから上を通して GPIO ヘッダーへ（約 17 cm）。`pi_base.stl` と `sensors.png`・組み立て図・配線図・`top.png`・`side.png` を更新
- プロジェクト説明の「ハードウェア構成」の構成ブロック図とデバイス一覧で、バッテリーを 2 個に分けて表示（「バッテリー（Pi 5 用）」→ DROK、「バッテリー（モーター用）」→ Motor HAT）。`architecture.yaml` のデバイスに `feeds`（電源の供給先）を追加し、図の線はそこから引く
- ダッシュボードの「プロジェクト説明」の右に「開発日記」ボタンを追加。main の記録（PR のマージ・直接のコミット）を日付ごとに新しい順に並べ、PR へのリンク、CHANGELOG に追加した行、印刷し直す STL、分類（3D プリント / 配線 / ダッシュボード / ソフト / ドキュメント、変更したファイルから判定）を表示し、分類で絞り込める。`GET /api/dev_diary`（`ai_car_web/dev_diary.py`、HEAD が変わるまでキャッシュ）。読むリポジトリは `dashboard_node.repo_dir`（空ならインストール先を含むワークスペース）
- ダッシュボードの見出しの横と、プロジェクト説明の「概要」タブ・PDF の表紙に「開発者：ひらかわたかし（GitHub: github.com/hirakawa-takashi）」を表示（`architecture.yaml` の `overview.developer` / `developer_github`、GitHub はリンク）
- 天板の上に 3 mm 出ているモーター取付ネジ（28 × 28 mm の範囲 4 か所、左右の端から 7 mm・前後の端から 38 mm）をよけるため、上に載る部品の底に 29 × 29 × 3.5 mm のくぼみを付けた（`motor_scr_pts`・`motor_recess()`）。前の 2 か所は箱（床を 3 → 5 mm にし、フランジだけの部分に 5 mm の台を追加。箱・ふた・LiDAR・カメラが 2 mm 高くなる。左の結束バンドの受けを Y 128 / 168 mm へ移動）、後ろ左はラズパイ台の左側のベース（3 → 5 mm。IMU・液晶が 2 mm 高くなる）。後ろ右は上に部品がないので変更なし。`box.stl`・`pi_base.stl`・`cover.stl`（ふたの縁のリブと LiDAR の抜きの高さ）と `side.png` を更新し、`motor_recess.png` を追加。組み立て図のふたの高さを 38.4 mm に変更
- バッテリー本体の残量表示（%）をカバーの外から見られるよう、ふた（15 × 14 mm）と上面カバー（17 × 16 mm、縁は 1 mm 面取り）に窓を開けた。位置は上のバッテリーの表示の実測（ポートの短辺から 7〜20 mm、右の長辺から 9 mm〜）に合わせた（`bat_disp`）。窓の上を通っていたカメラのフラットケーブルは、ふたの上で 45° に 2 回折って左へ 30 mm ずらし（後ろ半分は X 75〜91 mm、`fpc_rx`）、ふたの後ろ端から下りたあと DROK の上で右へ戻す。ブリッジは Y 168 mm（前半）と X 83・Y 128 mm（後ろ半分）へ移動。ケーブルの必要な長さは約 22 cm → 約 28 cm（300 mm で足りる）。LiDAR の USB 変換基板はふたの上の左寄りに貼る。`lid.stl`・`cover.stl` と組み立て図・配線図・カバーの画像を更新し、`battery_display.png` を追加
- 印刷の材料を PLA に合わせて、バンパーの板ばねを 1.2 mm から 0.8 mm に薄くした（4 mm 逃げたときのひずみ 1.6 % → 1.1 %、PLA の降伏ひずみ約 2 % の半分ほど）。ストッパーは 6.8 mm、前面の板は 0.4 mm 後ろへ。カバーのフック（ひずみ約 0.9 %）はそのまま。`bumper.stl` を更新し、材料の説明を PLA に変更
- 天板の厚さを実測の 2 mm に変更（`plate_t`、以前は 3 mm と仮定）。カバーのフックの爪が天板の裏から 1.2 mm 離れてがたつかないよう、爪の掛かり面を天板の裏から 0.2 mm に合わせた。`cover.stl`・`cover_hook.png` を更新
- 落下防止センサー（VL53L1X）の傾きを 30° から 45° に変更。床を見る位置がバンパーの前面から 1〜3 cm 先から 4〜8 cm 先になり、0.3 m/s でも止まる余裕ができる。上から落とし込む穴が天板の角にかからないよう、受けを 4.5 mm 前へ出した（`tof_dy` 14 mm）。`bumper.stl` を更新し、視野の図 `tof_view.png` を追加
- 3D プリントタブの「立体図（回して見る）」で、右ドラッグ（または Shift ＋ドラッグ）で注視点（回転の中心）をずらせるようにした。部品の切り替え・「向き・位置を戻す」・ダブルクリックで元に戻る
- バンパーの衝撃がネジに集中しないよう、左右の腕の下に爪を追加。前は箱のフランジの前の縁、後ろはラズパイ台の腕の端（平らな端を追加）に当て、左右 2 か所の面で受ける。`bumper.stl`・`pi_base.stl` を更新し、断面図 `bumper_hook.png` を追加
- 検出物体の距離で、カメラと LiDAR の取付位置の差を補正。3D マウントではカメラが LiDAR の中心より右 44 mm・前 53 mm にあり、同じ位置とみなすと方位が 1 m で約 2.5°、0.3 m で約 8° ずれていた。LiDAR の点をカメラから見た方位に直して照合する（新パラメータ `camera_offset_x_m` 0.053 / `camera_offset_y_m` −0.044。距離は LiDAR からの値のまま）
- ラズパイ台の液晶スタンドの左の支えと枠がベースの左端（X 4 mm）からはみ出して浮いていたため、ベース（`wing`）を X 1 mm まで広げてスタンド全体を載せる。`pi_base.stl` と `sensors.png` を更新
- 3D プリントタブの STL・画像が、ラズパイで更新したあとも古いまま表示されることがある問題を修正。`/` と `/print3d/*` に `Cache-Control: no-cache` を付け、`/api/architecture` の `print3d.rev`（print3d のファイルの最終更新時刻）を URL に `?v=` として付ける
- ラズパイ台の加速度センサー（GY-BNO055）の台を実物の基板 12 × 20 mm に合わせ、四方を壁で囲む形に変更（Pi 側の壁にケーブル穴 13 × 19 mm）。液晶の枠の底の下を台まで埋めて浮かないように変更。上面カバーとバンパーの手で触る縁に 1 mm の面取りを追加（外形は不変）。`pi_base.stl`・`bumper.stl`・`cover.stl` と組み立て図・配線図・カバー・バンパーの画像を更新
- カメラ（Camera Module 3）の取付を実物に合わせて正立（フラットケーブルが基板の下）に変更。箱の前面のボスをやめ、ふたの前端に立てた板（補強リブ 2 枚、ケーブルを通す下の窓付き）に M2 × 6 ×4 で留める。ケーブルは基板の下から後ろへ水平に折ってふたの上のブリッジへ。映像の 180° 回転は不要。カバーのカメラの窓は上面から前面までの切り欠きに変更（左の飾り窓は廃止）。`box.stl`・`lid.stl`・`cover.stl` と組み立て図・配線図を更新し、`camera_mount.png`・`camera_ribbon.png` を追加
- 天板全体を覆う上面カバー（`cover.stl`）を追加。工具不要で、左右 4 個のフックを天板の端の裏に引っかけて留める。右側面の充電口からカバーを付けたままバッテリーを充電できる。カメラ・液晶の窓、Pi の上の六角の通気口、LiDAR を付けたまま真上へ抜ける上面の抜き、「AI-CAR」の文字付き。K1C で一体で印刷できる（約 164 × 212 × 69 mm）
- 3D プリントタブの「立体図（回して見る）」に「組み立て図（カバー付き）」を追加（`print3d.assembly_views` に複数の組み立て図を指定できる。`assembly_view` 1 件も引き続き使える）
- 3D プリントタブの「立体図（回して見る）」に「組み立て図」を追加（最初に表示）。天板と 4 種類・5 個の部品を組み立てた位置に色分けして重ね、回して見られる。配置は `architecture.yaml` の `print3d.assembly_view`（部品ごとの `translate` / `rotate_z` / `flip_z`）で指定し、ブラウザで各 STL を移動して描画
- ラズパイ台の加速度センサー（GY-BNO055）の受けを、ピンヘッダー下向きに合わせて高さ 25 mm の台（四隅の柱 + 上端の位置決め枠、四方開放）に変更。画面を隠さないよう IMU を液晶の前へ、液晶を後ろへ入れ替え（`imu_lift` 25、`imu_c` [18, 64]、`lcd_y` 24）。`pi_base.stl` と組み立て図・配線図を更新
- プロジェクト説明に「3D プリント」タブを追加（`architecture.yaml` の `print3d`）。部品一覧（外形は STL から計算）、STL / OpenSCAD ソースのダウンロード、部品ごとの三面図（平面・正面・側面、寸法線付き）と立体図、ドラッグで回せる 3D 表示、印刷設定、ネジ一覧、組み立て手順、組み立て図・配線経路の画像を表示。`hardware/3d/battery_lidar_mount` の STL・PNG・SCAD を `share/ai_car_web/print3d` にインストールし、`GET /print3d/{file}` で配信
- Motor HAT 接続図の配線表に 1 本ごとの「備考」列を追加（Motor+ / Motor− は基板印字 M+ / M−、VCC / GND はエンコーダー電源 3V3 / GND、Encoder A / B は A 相（S1）/ B 相（S2）。`/api/motor_hat` の `wires[].note`）。回転・ドライバ情報は「回転 / ドライバ」列に分離
- エンコーダー VCC / GND の接続先表記を「Motor HAT (3V3 power)」「Motor HAT (Ground)」に統一（ピン番号表記「HAT pin 17 (3V3)」などを廃止。`/api/motor_hat` の `dest`・接続図・BOM・設定コメント）
- モーター 6 本の配線色をエンコーダー基板のコネクタ印字に基づき修正: Motor+（M+）黒 / Motor−（M−）赤 / VCC 白 / GND 黄 / Encoder A（S1）橙 / Encoder B（S2）緑（旧: Motor+ 緑 / Motor− 橙 / VCC 黄 / GND 白 / A 赤 / B 黒）。`motor_hat.yaml`・`gpio_pins.yaml`・`HARDWARE_BOM.md` を更新
- モーター 6 本の配線色をエンコーダー基板印字（M+ / M− / VCC / GND / S1 / S2）に基づき確定: Motor+ 緑 / Motor− 橙 / VCC 黄 / GND 白 / Encoder A（S1）赤 / Encoder B（S2）黒（旧: Motor− 白 / VCC 青 / GND 黒 / A 緑 / B 黄）。`motor_hat.yaml`・`gpio_pins.yaml`・`HARDWARE_BOM.md` を更新（接続図・一覧表・GPIO 表は YAML から描画されるため自動反映）
- プロジェクト説明モーダルのタイトル横に「PDF（全タブ一括）」ボタンを追加。7 タブの内容（配線図カード含む）を目次リンク・章ごとの改ページ付きの 1 ページにまとめて新規タブで開き、ブラウザの印刷から PDF 保存できる（印刷時は白背景・図は元配色）
- 電源を 12V→5.2V/5A 降圧コンバータに変更して低電圧が解消したため、カメラ取り込み・MJPEG 30fps、推論 15Hz、テレメトリ 10Hz、LiDAR 点群 720 点に戻す（IMU 20Hz、autonomy / joy 10Hz、液晶 2Hz は維持）。`config.txt` に `usb_max_current_enable=1` を設定
- CPU 使用率 20% 以下を目標に周期を見直し: カメラ取り込み 15fps（`FrameDurationLimits`）、推論 5Hz、テレメトリ 5Hz・LiDAR 点群 360 点（新パラメータ `scan_max_points`）、IMU 20Hz、autonomy / joy 10Hz、液晶 2Hz
- CPU 負荷軽減のためカメラ解像度を 1280×720 → 960×540 に変更（camera_node の JPEG 圧縮負荷を削減。検出側はレターボックスで 640×640 に揃えるため入力サイズ非依存）
- CPU 負荷軽減のため推論レート上限を 15 Hz（YOLOv8m の実効約 12 Hz は不変）、MJPEG 配信を 15 fps に変更（カメラ取り込みは 30 fps のまま）
- カメラ物体検出を YOLOv8m に変更し推論レートを 30 Hz に引き上げ（推論タイマー 0.2 s → 0.02 s で `inference_rate` 上限が実際に効くよう修正。従来は実効 5 Hz 上限）
- ダッシュボードにネイビー×シアンの計器パネル風テーマを適用（CSS のみ。カードのガラス風背景・数値の等幅フォント・状態バッジの発光・接続ドット / AUTO バッジのパルス・カメラ / LiDAR 枠のコーナーマーカー。レイアウトと表示内容は不変）
- GPIO 40 ピンヘッダー / Motor HAT 接続図カードをメイン画面からプロジェクト説明「ハードウェア構成」タブへ移動
- LiDAR (/scan) 表示の距離リングに数値ラベル（m）を追加
- プロジェクト説明ボタンと7タブの全画面モーダルを追加（`architecture.yaml` / `/api/architecture` による構成・安全機構・API・開発状況表示、dashboard.yaml の実値と生存ノード / Topic を反映）
- 運転モード切替・手動指令の安全停止を修正し、手動指令ウォッチドッグと起動時ゼロ出力、自律走行の後方距離未受信時の後退抑止、ダッシュボードの停止動作と任意トークン認証を追加
- ZJY-IPS130-V2.0（ST7789 1.3 インチ 240×240 IPS 液晶、SPI0、7 ピン CS なし）用 `lcd_display_node` を追加（spidev + libgpiod + Pillow。運転モード・自律行動・前方距離・障害物・電圧・CPU 温度・パッド接続・IP を描画、`/display_state` は従来コード互換）
- `gpio_pins.yaml` に ZJY-IPS130 液晶の配線色（GND 黒 / VCC 赤 / SCL 橙 / SDA 黄 / RES 緑 / DC 青 / BLK 紫）を設定
- 運転モード管理ノード `drive_mode_node` を追加（手動 / 自動 / 停止。`/cmd_vel_manual` と `/cmd_vel_auto` のどちらか一方だけを `/cmd_vel` に中継。`/drive_mode` 状態、`/drive_mode_request` 切替要求、自動進入条件・指令途絶・ゲームパッド切断時の安全停止）
- Level 1 自律走行ノード `autonomy_node` を追加（LiDAR 反応型: 前進 → 減速 → 空いている側へ旋回。`/cmd_vel_auto`、`/autonomy_status`）
- ゲームパッド: START 長押し 2 秒で手動 ⇄ 自動、BACK（自動中は B も）で停止
- ダッシュボード: 運転モードバッジ・3 ボタン（`GET/POST /api/drive_mode`）と自律走行カードを追加。7 セグに `AUto` / `StoP` を追加

### Changed
- 液晶（ZJY-IPS130-V2.0、ST7789）を構成から消した。`lcd_display_node.py`・`setup.py` の入口・`dashboard.launch.py` の `use_lcd_display`・`dashboard.yaml` の `lcd_display_node`・`gpio_pins.yaml` の液晶の 7 本（pin 16/17/18/19/20/22/23）・`architecture.yaml` の機器 / ノード / マイルストーン / 技術スタック・ダッシュボードの図の液晶・README のセットアップ・HARDWARE_BOM の行を消した。ハードウェア構成図のカメラの線を CSI → USB に直した
- 液晶（ZJY-IPS130-V2.0）を取り外したので、`dashboard.launch.py` の `use_lcd_display` の既定を `false` にした。液晶を戻すときは `use_lcd_display:=true`。IMU（GY-BNO055）は付けたまま
- `autonomy_node` の `scan_angle_offset_deg` の既定値を 180° → 0° にした（dashboard_node・perception_node の既定値とそろえる。dashboard.yaml を読まずに起動したときも前後が逆にならない）
- LiDAR の向きの補正 `scan_angle_offset_deg` を 180° → 0° にした（dashboard_node・autonomy_node・perception_node）。3D マウントでモーター側を前に向けたため、以前の取り付け（前が車体の後ろ向き）の 180° 補正で、点群の表示と前方の判定が前後逆になっていた（実機で確認）
- 試験台の車輪と車軸の寸法を、部品リストの製品（OSOYOO FlexiRover 520 モーター版）の図面の値にした。車輪の直径 80 → 80.59 mm（幅 39.1 mm）、車軸は天板の前後の端から 56 → 52 mm（シャーシ 1 段目の図面のモーターの台の穴 Y 37 / 67 mm）。受け面の奥行き（車輪の手前 1 mm まで）は 15 → 10.7 mm に縮むので、左右の幅を 25 → 40 mm に広げた（天板の下のモーターの台は Y 32 mm から）。受け面の天板の 4 隅の穴（Ø4.4）の下に Ø12 × 深さ 12 mm のくぼみを付け、上の部品を留めるネジの先・ナットをよける。`test_stand.stl` と画像を更新
- 箱の開口側の角にあるふたのボス 2 本が、開口の切り抜きで内側 2.5 mm 欠けていた（M3 のねじ込み穴の壁が 0.25 mm）のを、欠けのない円柱（壁 2.75 mm）に戻した。ボスはバッテリーの通り道にかかるため、バッテリーはふたを外して上から出し入れする（説明と `architecture.yaml` を修正）。印刷し直すのは `box.stl`
- `perception_node` のカメラ推論を YOLOv8m（640x640 / 78.9 GOP）へ更新。レターボックス前処理でアスペクト比を維持し、検出枠を元画像座標へ復元。信頼度 0.5 と複数フレーム確認（履歴3フレーム中2回）で誤検出を抑制
- 状態表示器を TM1637 7 セグから ZJY-IPS130-V2.0 液晶へ置き換え（launch 既定 `use_lcd_display=true` / `use_seg_display=false`。`gpio_pins.yaml`・BOM・README の配線を pin 16/17/18/19/20/22/23 の液晶接続に更新）
- `dashboard_node` の手動指令出力を `/cmd_vel` から `/cmd_vel_manual` に変更（`/cmd_vel` は `drive_mode_node` が発行）
- Motor HAT 接続図・一覧表を 1 モーター 6 本（Motor+ / Motor− / VCC / GND / Encoder A / Encoder B）すべて明示する形に変更（`/api/motor_hat` に `wires`）。エンコーダー VCC / GND は Motor HAT 上の 3V3 / GND ピンへ（`motor_hat.yaml` `hat.encoder.power_board`）
- OSOYOO 520 モーターの配線色をメーカー資料どおり（赤 Motor+ / 白 Motor− / 青 VCC / 黒 GND / 緑 Encoder A / 黄 Encoder B）に修正し、車輪表記を進行方向基準の「M1 前左」形式に統一
- OSOYOO 520 モーターエンコーダー（A/B 相）の Pi GPIO 直結割り付けを `motor_hat.yaml`（`encoder`）と `gpio_pins.yaml` に追加し、Motor HAT 接続図・一覧表・GPIO ヘッダー図に表示
- ダッシュボードに Motor HAT 接続図カードを追加（`config/motor_hat.yaml` で M1〜M4 と車輪位置を割り付け、`GET /api/motor_hat` で取得）
- TM1637 4桁7セグメントLED用 `seg_display_node` を追加し、ロボット状態コードを表示
- GY-BNO055 用 `imu_node` を追加し、I2C（0x29）から `/imu/data` を publish
- `gpio_pins.yaml` の BNO055 配線色を SDA 白 / SCL 灰へ更新
- ai_car_description パッケージを新規作成
  - CMakeLists.txt (ament_cmakeベース)、package.xml
  - urdf/ai_car.xacro: メカナム4輪・LiDAR・カメラ・IMU を含むロボット記述
  - launch/view_robot.launch.py: robot_state_publisher / joint_state_publisher（use_gui・use_rviz・use_sim_time 引数）
  - rviz/ai_car.rviz: RobotModel / TF / LaserScan 表示設定
  - ディレクトリ構造: config/, launch/, meshes/, rviz/, urdf/
- ai_car_web パッケージを新規作成（FastAPI Webダッシュボード）
  - dashboard_node: `/cmd_vel` publish、`/scan`・`/imu/data`・`/odom` 購読
  - REST API: `/api/status`, `/api/cmd_vel`, `/api/stop`、WebSocket `/ws`
  - static/index.html: メカナム操作UIとテレメトリ表示
  - config/dashboard.yaml、launch/dashboard.launch.py
  - 無指令タイムアウトによる自動停止
- LiDAR (`/scan`) の360度スキャンを点群マップ（Canvas）で表示し、LiDAR カードをカメラの次に配置
  - `dashboard_node`: LaserScan を直交座標の点群（最大720点に間引き）へ変換して `/api/status` の `scan.points` で配信
  - `dashboard.launch.py`: `rplidar_ros`（`rplidar_composition`）を `use_lidar` 引数で起動
  - `config/dashboard.yaml`: RPLIDAR のシリアルポート（by-id）・ボーレート・`frame_id` を追加
- 障害物判定ノード `perception_node` を新規作成（LiDAR 主・カメラ/AI HAT+ 補助）
  - `/scan` の前方 ±30°（`front_angle_deg`）を左/中央/右セクターに分けて最近距離を算出し、`stop_distance`（0.35m）/`slow_distance`（0.8m）で 停止 / 減速 / 安全 / 不明 を判定
  - `/camera/image_raw/compressed` を Hailo-8（`yolov8n.hef`、HailoRT 4.24 Python バインディング）で推論し、前方に写る物体名を補足情報として付与（推論約8ms）
  - サーマルガバナ: CPU 70℃ / AI HAT+ 75℃ で推論レートを 40% に低下、CPU 78℃ / AI HAT+ 85℃ で推論停止（LiDAR による安全判定は継続）
  - 判定結果を `/obstacle_status`（std_msgs/String, JSON）で 5Hz publish。距離・推論レート・温度閾値は実行中にパラメータ変更可能
  - `dashboard_node` が `/obstacle_status` を購読して `/api/status` の `obstacle` で配信し、前進指令に `speed_scale` を適用（`obstacle_guard`）
  - index.html に「障害物判定（LiDAR 主 / AI HAT+ 補助）」カードを追加
  - `dashboard.launch.py` に `use_perception` 引数を追加
  - 検出物体の距離を LiDAR と連動して算出（画像の横位置を `camera_hfov_deg`（66°）で方位角へ変換し、その角度範囲の最近距離を採用）
  - カメラ映像に検出枠と距離をオーバーレイ表示。`danger_distance`（0.3m）以内は赤枠、それ以外は緑枠
  - LiDAR 点群マップで `danger_distance` 以内かつ前方セクター（`front_angle_deg` 60°）内の点のみ赤点で強調
  - `scan_angle_offset_deg`（既定0°）で LiDAR 取り付け向きを補正可能にし、点群マップに前方／後方／左／右のラベルを表示
- CPU カードに入力電圧（`EXT5V`）・入力電流・電源状態を追加。入力電流は PMIC が EXT5V の電流を出さないため各レールの合計電力から換算する。`vcgencmd get_throttled` の低電圧 / スロットリング / クロック制限 / 温度制限をバッジで表示し、現在発生中は赤・起動後に発生した場合は黄色で警告する（電源不足による突然の電源断を事前に気付けるため）
- `ai-car-dashboard.service` の停止シグナルを SIGINT にし、起動前に `/dev/ttyUSB0` の解放を待つようにした（`systemctl restart` 時に前回の `rplidar_composition` がポートを掴んだままで LiDAR 初期化がタイムアウトし、スキャンが流れなくなるため）
- 速度指令 (/cmd_vel) とオドメトリ (/odom) のカードを削除し、AI HAT+ カードと IMU カードを同じ列に縦積み（AI HAT+ は内容分の高さのみ）に変更
- 動体のぶれ（残像）低減のため、カメラの露光を手動 8ms 固定（`ExposureTimeMode: 1` / `ExposureTime: 8000`）＋アナログゲイン自動（`AnalogueGainMode: 0`）に変更。室内では AE が露光を 1 フレーム分（33ms）まで伸ばすため。高ゲイン時のノイズ対策に `NoiseReductionMode: 1`（Fast）も有効化
- 障害物判定カードを廃止し、内容（レベル＋前方距離、検出物体、左/中/右、速度制限、推論時間＋サーマル）をカメラカードに統合。受信フレーム数と1枚あたりサイズは fps 行のツールチップへ移動
- カメラカードに解像度・fps（ROS 受信の実測 / MJPEG 配信上限）・1枚あたりの JPEG サイズを表示。あわせて映像枠のアスペクト比を実解像度に追従させ、16:9 化で生じていた検出枠の縦ずれを解消
- 映像を滑らかにするためカメラを 1280x720 / JPEG 品質 80 に変更し、MJPEG 配信を 10fps から 30fps へ引き上げた。配信ループは同間隔スリープだと位相ずれで実効レートが半減するため、短周期監視＋送信間隔保持に変更
- 検出枠の追従を滑らかにするため推論を 4Hz → 10Hz、テレメトリを 5Hz → 10Hz、ポーリングフォールバックを 1s → 250ms に変更
- AI HAT+ カードに推論レート（現在 / 連続実行時）と実効 TOPS の推定値を表示。`perception_node` が `obstacle.throughput` として配信し、`model_gops`（既定 8.7 = YOLOv8n 640x640）× 推論レートで換算する。Hailo は実効 TOPS を報告しないため推定値
- CPU ファンの作動温度を 45/50/55/62℃ へ前倒しする `scripts/set_fan_curve.sh` と `systemd/ai-car-fan.service` を追加
- CPU カードにファン回転数と段階（`cpu.fan`）を表示
- カード内の表を1行固定にし（`table-layout: fixed` ＋ 省略記号）、障害物判定カードの項目名・値を短縮。検出物体は先頭1件＋「他N」表示とし全件は title に保持
- CPU カードのロードアベレージ表示を削除し、代わりに PD 対応（5A）の 〇 / × 表示を追加。`vcgencmd get_config usb_max_current_enable` を `power.pd_5a` として配信する
- AI HAT+ カードから PCIe リンク使用率・リンク速度の表示を削除し、温度をカード最上部に移動
- ダッシュボードの CPU / AI HAT+ の温度を横バーグラフ表示に変更（0–100℃ スケール、70℃ で警告色、85℃ で危険色）
- AI HAT+ (Hailo-8) のオンチップ温度を HailoRT C API `hailo_get_chip_temperature()`（ctypes 直接呼び出し）で取得し、ダッシュボードの温度欄に表示（ts0/ts1 の平均）
- system_monitor_node を新規作成（Raspberry Pi 5 / AI HAT+ 監視）
  - CPU使用率（全体・コア別）・クロック・温度・ロードアベレージ
  - メモリ・Swap・ディスク使用量
  - `vcgencmd pmic_read_adc` による電源レール別の電圧・電流・電力と合計消費電力
  - `vcgencmd get_throttled` のスロットリング状態（現在・過去）
  - AI HAT+ (Hailo-8) の PCIe 検出状態、`hailo_pci` ドライバ版数と PCIe リンク速度・幅、HailoRT 導入済みなら FW 版数・アーキテクチャ
  - `/system_status`（std_msgs/String, JSON）を 1Hz で publish
  - dashboard_node が `/system_status` を購読し、REST / WebSocket の `system` フィールドで配信
  - index.html に CPU / メモリ / 電源 / AI HAT+ のカードを追加
- プロジェクト管理ファイルを作成
  - PROJECT_RULES.md: 開発方針・禁止事項
  - PROJECT_STATUS.md: 実装状況・課題管理
  - CHANGELOG.md: 本ファイル
- `systemd/ai-car-dashboard.service` と `systemd/install_service.sh` を追加し、ダッシュボードを起動時に自動起動（`Restart=always`、USB デバイス待ちで10秒遅延）
- README に Ubuntu 24.04 向け AI HAT+ セットアップ手順（hailort-drivers v4.24.0 と HailoRT 4.24.0 のソース導入）を追記
- カメラ映像をダッシュボードに追加
  - `dashboard_node` が `/camera/image_raw/compressed`（`sensor_msgs/CompressedImage`）を購読
  - `GET /api/camera/snapshot`（JPEG）と `GET /api/camera/stream`（MJPEG）を追加
  - index.html にカメラカード（映像・状態・受信フレーム数・最終受信時刻）を追加
  - `dashboard.launch.py` に `use_camera` 引数を追加し、`camera_ros` があればカメラノードを起動。`~/opt/rpicam` の Raspberry Pi 版 libcamera を `LD_LIBRARY_PATH` に自動追加
  - README に Ubuntu 24.04 向けカメラ（IMX708）セットアップ手順（Raspberry Pi 版 libcamera / libpisp のビルド）を追記

### Changed
- AI HAT+ カードを Raspberry Pi 5 — CPU カードと同じ構成（使用率バー＋4行テーブル＋詳細グリッド）に統一。PCIe リンク使用率（現在幅/最大幅）とリンク速度（現在/最大）を追加し、デバイス・FW・ドライバ・PCIe アドレスを下部グリッドに表示
- 表記を AI-CAR に統一（旧 AT-CAR）
- ダッシュボードの表示順を Raspberry Pi 5 — CPU、AI HAT+ — Hailo-8 NPU の順に変更
- ダッシュボードのカード順を カメラ → LiDAR → CPU → AI HAT+ に変更し、カメラと LiDAR のカードを横幅 2 列分（`grid-column: span 2`、620px 以下では 1 列）に拡大
- 全体消費電力を CPU カードの温度の下に移動し、電源 (PMIC) とメモリ / ストレージのカードを削除（`/system_status` の `memory` / `power` 収集自体は継続）

### Fixed
- Jetson `owl_detector.py`: AI-CAR のダッシュボード再起動中に画像が途中で切れる（`http.client.IncompleteRead`）と、例外を拾えずに止まり、自動で戻らなかった。通信エラーとして扱い、1 秒後に取り直す
- ラズパイ台の液晶スタンドを実物に合わせた。溝の幅を 0.6 mm 広げ（基板 27.5 → 28.1 mm、`lcd_board`）、基板の下端の裏のピンヘッダーが台に当たらないよう、溝の底を 10 mm 上げた（`lcd_raise`、垂直方向）。枠と左右の支えも同じだけ長くし、上端は天板から約 52.5 mm。`pi_base.stl`・`sensors.png` を更新
- バッテリー箱の内寸を、バッテリーの実測（98.2 × 66.8 mm）に合わせた。前後のすき間が片側 1.7 mm あってがたついていたので、前後の壁を内側へ 1.3 mm 厚くして片側 0.4 mm にした（外形は変えない）。上のバッテリーが 1.1 mm 前へ寄るので、ふたとカバーの残量表示の窓もずらした。印刷し直すのは box.stl・lid.stl・cover.stl
- 「PDF（全タブ一括）」の「組み立て図・配線経路」で、画面に出ていない画像（遅延読み込み）が印刷時に空白になっていたのを修正（PDF では遅延読み込みをやめる）。あわせて、印刷時に画像の説明文が黒地に黒字で読めなかったのを白地に黒字にした
- LiDAR の取り付け向きに合わせて `scan_angle_offset_deg` を 180° に設定し、点群マップの前後反転と前方距離の誤りを解消
- カメラ検出物体の距離を、方位角範囲内の点を距離でクラスタリングして最も手前のまとまりの中央値から求めるようにし、単発の外れ点で極端に近い距離（例: 実距離約2.7mに対し0.17m）を表示しないようにした。スキャンが `scan_max_age`（1秒）より古い場合は距離を出さない
- カメラ / LiDAR ノードを `respawn` 対応にし、デバイス切断などで落ちても自動復帰するようにした
- Hailo の状態判定を `hailortcli` の有無ではなく `/dev/hailo0` の存在で行うように変更。AI HAT+ 非対応の温度取得呼び出しを削除
- WebSocket が利用できない環境（uvicorn に websockets/wsproto 未導入）では `/api/status` の1秒ポーリングへ自動フォールバックするようにした

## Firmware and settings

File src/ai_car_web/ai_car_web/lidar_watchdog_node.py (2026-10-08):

#!/usr/bin/env python3
"""/scan が途絶えたら rplidar ノードを終了させ、launch の respawn で起動し直させるノード。

rplidar_ros は USB（CP2102）が抜けて差し直されると、古いシリアルポートを
握ったまま /scan を出さなくなり、プロセスは生きたままになる。
scan_timeout 秒 /scan が来なければ rplidar_composition に SIGTERM を送り、
kill_wait 秒たっても残っていれば SIGKILL を送る。起動直後と再起動の後は
startup_grace 秒待ってから監視する。

電池の電圧が下がった後などに CP2102 が返事をしなくなると、起動し直しても
/scan は戻らない。usb_reset_after 回続けて戻らなければ、rplidar を止めた後に
LiDAR の USB をつなぎ直す（USBDEVFS_RESET。/dev/bus/usb の書き込み権限は udev ルールで付ける）。

CP2102 が固まると USBDEVFS_RESET でも戻らない（2026-10-08 は約 10 時間 45 分）。
power_cycle_after 回続けば、USB の電気を切って入れ直す（power_cycle_cmd、power_cycles 回まで）。
reboot_after 回続けば、ラズパイを再起動する（reboot_cmd）。再起動は、この起動で /scan が
一度でも来ていて、起動から reboot_min_uptime 秒たっているときだけ（LiDAR がないときや、
再起動しても直らないときに、くり返さない）。
"""

import fcntl
import glob
import os
import signal
import subprocess
import time

import rclpy
from rclpy.node import Node
from rclpy.qos import qos_profile_sensor_data
from sensor_msgs.msg import LaserScan

USBDEVFS_RESET = ord('U') << 8 | 20


def find_pids(pattern: str):
    pids = []
    for name in os.listdir('/proc'):
        if not name.isdigit() or int(name) == os.getpid():
            continue
        try:
            with open(f'/proc/{name}/cmdline', 'rb') as f:
                cmdline = f.read().replace(b'\0', b' ').decode(errors='replace')
        except OSError:
            continue
        if pattern in cmdline:
            pids.append(int(name))
    return pids


def _read(path):
    try:
        with open(path) as f:
            return f.read().strip()
    except OSError:
        return None


def find_usb_device(vendor: str, product: str):
    """idVendor / idProduct が合う USB 機器の /dev/bus/usb のパス。なければ None。"""
    for d in sorted(glob.glob('/sys/bus/usb/devices/*')):
        if _read(f'{d}/idVendor') != vendor or _read(f'{d}/idProduct') != product:
            continue
        bus, dev = _read(f'{d}/busnum'), _read(f'{d}/devnum')
        if bus and dev:
            return f'/dev/bus/usb/{int(bus):03d}/{int(dev):03d}'
    return None


def uptime_seconds():
    try:
        with open('/proc/uptime') as f:
            return float(f.read().split()[0])
    except (OSError, ValueError, IndexError):
        return 0.0


def reset_usb(path: str):
    fd = os.open(path, os.O_WRONLY)
    try:
        fcntl.ioctl(fd, USBDEVFS_RESET, 0)
    finally:
        os.close(fd)


class LidarWatchdogNode(Node):
    def __init__(self):
        super().__init__('lidar_watchdog_node')
        self.declare_parameter('scan_topic', '/scan')
        self.declare_parameter('scan_timeout', 3.0)
        self.declare_parameter('startup_grace', 15.0)
        self.declare_parameter('kill_wait', 3.0)
        self.declare_parameter('process_pattern', 'rplidar_ros/rplidar_composition')
        self.declare_parameter('usb_reset_after', 2)
        self.declare_parameter('usb_vendor_id', '10c4')
        self.declare_parameter('usb_product_id', 'ea60')
        self.declare_parameter('power_cycle_after', 4)
        self.declare_parameter('power_cycles', 2)
        self.declare_parameter('power_cycle_cmd', ['sudo', '-n', '/usr/local/sbin/ai-car-usb-power-cycle'])
        self.declare_parameter('reboot_after', 7)
        self.declare_parameter('reboot_min_uptime', 1800.0)
        self.declare_parameter('reboot_cmd', ['sudo', '-n', '/usr/bin/systemctl', 'reboot'])

        self.scan_timeout = float(self.get_parameter('scan_timeout').value)
        self.startup_grace = float(self.get_parameter('startup_grace').value)
        self.kill_wait = float(self.get_parameter('kill_wait').value)
        self.pattern = str(self.get_parameter('process_pattern').value)
        self.usb_reset_after = int(self.get_parameter('usb_reset_after').value)
        self.usb_id = (str(self.get_parameter('usb_vendor_id').value),
                       str(self.get_parameter('usb_product_id').value))
        self.power_cycle_after = int(self.get_parameter('power_cycle_after').value)
        self.power_cycles = int(self.get_parameter('power_cycles').value)
        self.power_cycle_cmd = list(self.get_parameter('power_cycle_cmd').value)
        self.reboot_after = int(self.get_parameter('reboot_after').value)
        self.reboot_min_uptime = float(self.get_parameter('reboot_min_uptime').value)
        self.reboot_cmd = list(self.get_parameter('reboot_cmd').value)

        self._last_scan = None
        self._watch_from = time.monotonic() + self.startup_grace
        self._term_pids = []
        self._term_at = None
        self._restarts = 0
        self._fails = 0
        self._scan_seen = False
        self._rebooting = False

        self.create_subscription(
            LaserScan, str(self.get_parameter('scan_topic').value),
            self._scan_cb, qos_profile_sensor_data)
        self.create_timer(0.5, self._tick)

    def _scan_cb(self, _msg):
        self._last_scan = time.monotonic()
        self._fails = 0
        self._scan_seen = True

    def _tick(self):
        now = time.monotonic()
        if self._term_at is not None:
            if now - self._term_at < self.kill_wait:
                return
            alive = [p for p in self._term_pids if p in find_pids(self.pattern)]
            for pid in alive:
                self.get_logger().warn(f'rplidar（pid {pid}）が終わらないので SIGKILL を送ります')
                if self._fails <= 1:
                    self.get_logger().warn(f'rplidar（pid {pid}）のスレッドの待ち先: {thread_waits(pid)}')
                self._signal(pid, signal.SIGKILL)
            self._recover()
            self._term_pids, self._term_at = [], None
            self._last_scan = None
            self._watch_from = now + self.startup_grace
            return
        if now < self._watch_from:
            return
        age = now - max(self._last_scan or 0.0, self._watch_from)
        if age < self.scan_timeout:
            return
        pids = find_pids(self.pattern)
        if not pids:
            self._watch_from = now + self.startup_grace
            return
        self._restarts += 1
        self._fails += 1
        self.get_logger().warn(
            f'/scan が {age:.1f} 秒来ないので rplidar を起動し直します（{self._restarts} 回目）')
        for pid in pids:
            self._signal(pid, signal.SIGTERM)
        self._term_pids, self._term_at = pids, now

    def _recover(self):
        if 0 < self.reboot_after <= self._fails and self._reboot():
            return
        if (0 < self.power_cycle_after <= self._fails < self.power_cycle_after + self.power_cycles
                and self._power_cycle()):
            return
        if 0 < self.usb_reset_after <= self._fails:
            self._reset_usb()

    def _run(self, cmd, what):
        try:
            r = subprocess.run(cmd, capture_output=True, text=True, timeout=20)
        except (OSError, subprocess.TimeoutExpired) as e:
            self.get_logger().error(f'{what}できません: {e}')
            return False
        if r.returncode != 0:
            self.get_logger().error(
                f'{what}できません（{r.returncode}）: {(r.stderr or r.stdout).strip()[:200]}')
            return False
        return True

    def _power_cycle(self):
        if find_usb_device(*self.usb_id) is None:
            return False
        self.get_logger().warn(
            f'起動し直しても /scan が {self._fails} 回戻らないので、USB の電気を切って入れ直します'
            '（ゲームパッドも数秒切れます）')
        return self._run(self.power_cycle_cmd, 'USB の電気を切って入れ直し')

    def _reboot(self):
        if self._rebooting:
            return True
        if not self._scan_seen or uptime_seconds() < self.reboot_min_uptime:
            return False
        self.get_logger().error(
            f'USB の電気を入れ直しても /scan が {self._fails} 回戻らないので、ラズパイを再起動します')
        self._rebooting = self._run(self.reboot_cmd, 'ラズパイを再起動')
        return self._rebooting

    def _reset_usb(self):
        path = find_usb_device(*self.usb_id)
        if path is None:
            self.get_logger().error(f'LiDAR の USB（{":".join(self.usb_id)}）が見つかりません')
            return
        try:
            reset_usb(path)
        except OSError as e:
            self.get_logger().error(f'LiDAR の USB（{path}）をつなぎ直せません: {e}')
            return
        self.get_logger().warn(
            f'起動し直しても /scan が {self._fails} 回戻らないので、LiDAR の USB（{path}）をつなぎ直しました')

    def _signal(self, pid, sig):
        try:
            os.kill(pid, sig)
        except ProcessLookupError:
            pass
        except PermissionError as e:
            self.get_logger().error(f'rplidar（pid {pid}）を止められません: {e}')


def thread_waits(pid):
    """プロセスの各スレッドが kernel のどこで待っているか（wchan）を「名前:待ち先×数」にする。"""
    counts = {}
    for task in sorted(glob.glob(f'/proc/{pid}/task/*')):
        try:
            with open(f'{task}/comm') as f:
                name = f.read().strip()
            with open(f'{task}/wchan') as f:
                wchan = f.read().strip() or '-'
        except OSError:
            continue
        key = f'{name}:{wchan}'
        counts[key] = counts.get(key, 0) + 1
    return ', '.join(f'{k}×{n}' for k, n in counts.items()) or '不明'


def main(args=None):
    rclpy.init(args=args)
    node = LidarWatchdogNode()
    try:
        rclpy.spin(node)
    except KeyboardInterrupt:
        pass
    finally:
        node.destroy_node()
        if rclpy.ok():
            rclpy.shutdown()


if __name__ == '__main__':
    main()

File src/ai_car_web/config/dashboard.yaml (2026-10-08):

dashboard_node:
  ros__parameters:
    host: "0.0.0.0"
    port: 8080
    # 手動指令（Web + ゲームパッド）。drive_mode_node がモードに応じて /cmd_vel へ中継する
    cmd_vel_topic: "/cmd_vel_manual"
    scan_topic: "/scan"
    imu_topic: "/imu/data"
    odom_topic: "/odom"
    system_status_topic: "/system_status"
    camera_topic: "/camera/image_raw/compressed"
    stereo_depth_topic: "/stereo/depth_status"
    stereo_depth_image_topic: "/stereo/depth/compressed"
    # ブラウザへの MJPEG 配信レート（カメラ取り込み 15fps と同じ）
    camera_stream_rate: 30.0
    obstacle_topic: "/obstacle_status"
    obstacle_guard: true
    # LiDAR の取り付け向きの補正。画面の「前方」= 前方カメラの正面。カメラの画面の真ん中に置いたボトルが
    # LiDAR で右 4°・0.47 m に見えたことから求めた値（2026/10 実機で測定）。perception / autonomy も同じ値にする
    scan_angle_offset_deg: -1.7
    max_linear_speed: 0.3
    max_angular_speed: 1.0
    cmd_timeout: 0.7
    # CPU 負荷軽減のため画面更新 5Hz、LiDAR 点群は 360 点に間引き
    telemetry_rate: 10.0
    scan_max_points: 720
    # 40 ピンヘッダーの配線表。空なら share/ai_car_web/config/gpio_pins.yaml
    gpio_config: ""
    # Motor HAT の M1〜M4 と車輪の割り付け。空なら share/ai_car_web/config/motor_hat.yaml
    motor_hat_config: ""
    # プロジェクト説明の構成定義。空なら share/ai_car_web/config/architecture.yaml
    architecture_config: ""
    # 構成定義から参照する ROS パラメータ。空なら share/ai_car_web/config/dashboard.yaml
    params_config: ""
    # 開発日記（/api/dev_diary）で読む git リポジトリ。空ならインストール先を含むリポジトリ（ワークスペース）
    repo_dir: ""
    # ゲームパッドの正規化指令（joy_teleop_node）。この秒数以上途絶えると未接続表示
    joy_cmd_topic: "/joy_cmd"
    joy_timeout: 1.0
    drive_mode_topic: "/drive_mode"
    drive_mode_request_topic: "/drive_mode_request"
    api_token: ""  # 空なら認証なし。設定すると POST /api/* に X-API-Token（または Bearer）ヘッダーが必要。環境変数 AI_CAR_API_TOKEN でも指定可
    autonomy_status_topic: "/autonomy_status"
    cliff_topic: "/cliff_status"
    # SLAM（slam_toolbox、use_slam:=true）の地図・自己位置と、地図の保存先
    map_topic: "/map"
    slam_pose_topic: "/pose"
    slam_save_service: "/slam_toolbox/save_map"
    map_save_dir: "/home/super/AI-CAR_ws/maps"
    # Jetson（jetson/owl_detector）から POST /api/jetson/detections で受けた物体検出を流すトピック
    jetson_detections_topic: "/jetson_detections"

drive_mode_node:
  ros__parameters:
    # 運転モード（manual / auto / stop）を管理し、/cmd_vel を発行する唯一のノード
    cmd_vel_topic: "/cmd_vel"
    manual_topic: "/cmd_vel_manual"
    auto_topic: "/cmd_vel_auto"
    request_topic: "/drive_mode_request"
    mode_topic: "/drive_mode"
    obstacle_topic: "/obstacle_status"
    joy_cmd_topic: "/joy_cmd"
    initial_mode: "manual"
    publish_rate: 5.0
    auto_timeout: 0.5        # 自動指令が途絶えたら STOP
    manual_timeout: 1.0      # 手動指令が途絶えたら STOP
    obstacle_timeout: 2.0    # 障害物判定が途絶えたら LiDAR 停止とみなす
    joy_timeout: 1.0
    auto_requires_joy: true  # ゲームパッド切断で AUTO → STOP
    manual_override: true    # AUTO 中の手動指令で MANUAL へ復帰
    obstacle_guard: true     # 最終段で stop 判定中の前進を止める
    cliff_topic: "/cliff_status"
    cliff_guard: true        # 段差を検出した向き（前 / 後）への移動を止め、AUTO は STOP
    cliff_timeout: 1.0       # 段差判定がこれより古ければ使わない（配線済みなら AUTO を拒否 / STOP）

autonomy_node:
  ros__parameters:
    # Level 1: LiDAR 反応型（地図なし）。AUTO モードのときだけ /cmd_vel に中継される
    scan_topic: "/scan"
    obstacle_topic: "/obstacle_status"
    drive_mode_topic: "/drive_mode"
    cmd_topic: "/cmd_vel_auto"
    status_topic: "/autonomy_status"
    publish_rate: 10.0   # 判断周期 0.1s（停止距離 0.35m・巡航 0.15m/s に対して十分）
    scan_angle_offset_deg: -1.7   # dashboard_node と同じ値
    scan_max_age: 1.0
    cruise_speed: 0.15
    slow_speed: 0.08
    turn_speed: 0.6
    backoff_speed: 0.08
    front_angle_deg: 60.0
    stop_distance: 0.35
    slow_distance: 0.8
    clear_distance: 0.9
    backoff_distance: 0.25
    min_turn_sec: 0.6

joy_teleop_node:
  ros__parameters:
    # Logitech F710（背面スイッチ X = XInput モード）
    device: "/dev/input/js0"
    joy_cmd_topic: "/joy_cmd"
    publish_rate: 10.0
    deadzone: 0.15
    # 通常の出力割合。RB を押している間は全速
    speed_scale: 0.5
    axis_linear_x: 1    # 左スティック上下: 前進/後退
    axis_linear_y: 0    # 左スティック左右: 平行移動
    axis_angular_z: 3   # 右スティック左右: 旋回
    axis_dpad_x: 6
    axis_dpad_y: 7
    button_turbo: 5     # RB
    button_stop: 1      # B: 押している間は停止
    button_enable: -1   # デッドマンボタン（-1 で無効。例: 4 = LB）
    # 運転モード切替（drive_mode_node への要求）
    mode_request_topic: "/drive_mode_request"
    mode_topic: "/drive_mode"
    button_mode_toggle: 7   # START 長押しで手動 ⇄ 自動
    button_estop: 6         # BACK で即時停止
    mode_hold_sec: 2.0

seg_display_node:
  ros__parameters:
    # TM1637: VCC=17、GND=20、CLK=16(GPIO23)、DIO=18(GPIO24)
    gpio_chip: ""
    clk_gpio: 23
    dio_gpio: 24
    brightness: 2
    update_rate: 5.0
    system_status_topic: "/system_status"
    obstacle_topic: "/obstacle_status"
    joy_cmd_topic: "/joy_cmd"
    cmd_vel_topic: "/cmd_vel"
    state_topic: "/display_state"
    status_timeout: 3.0
    drive_mode_topic: "/drive_mode"
    # 表示コード: boot 起動待ち / rdy 待機 / HAnd 手動 / AUto 自動 / StoP 停止モード
    #             ObSt 障害物停止 / SLo 減速 / LoU 低電圧 / Err システム状態未受信
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

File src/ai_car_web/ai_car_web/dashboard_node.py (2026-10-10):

"""AI-CAR Webダッシュボードノード。

FastAPI サーバーを別スレッドで起動し、ブラウザ・ゲームパッドからの手動操作コマンドを
手動指令トピック（既定 /cmd_vel_manual。drive_mode_node がモードに応じて /cmd_vel へ中継）
へ publish し、センサートピックのテレメトリを WebSocket で配信する。
"""

import asyncio
import hmac
import json
import math
import os
import struct
import subprocess
import threading
import time
import urllib.error
import urllib.parse
import urllib.request
import zlib
from collections import deque

import rclpy
import uvicorn
import yaml
from ament_index_python.packages import get_package_share_directory
from fastapi import Depends, FastAPI, HTTPException, Request, WebSocket, WebSocketDisconnect
from fastapi.responses import FileResponse, Response, StreamingResponse
from fastapi.staticfiles import StaticFiles
from geometry_msgs.msg import PoseWithCovarianceStamped, Twist
from nav_msgs.msg import OccupancyGrid, Odometry
from pydantic import BaseModel
from rclpy.node import Node
from rclpy.qos import QoSDurabilityPolicy, QoSHistoryPolicy, QoSProfile, QoSReliabilityPolicy
from sensor_msgs.msg import CompressedImage, Imu, LaserScan
from std_msgs.msg import String
from std_srvs.srv import Trigger

from ai_car_web.architecture import load_architecture
from ai_car_web.dev_diary import find_repo, load_dev_diary
from ai_car_web.gpio_pinout import build_pinout
from ai_car_web.motor_hat import load_motor_hat

try:
    from slam_toolbox.srv import SaveMap
except ImportError:
    SaveMap = None


MAX_SCAN_POINTS = 720


class CmdVelRequest(BaseModel):
    """ブラウザから受け取る速度指令。"""

    linear_x: float = 0.0
    linear_y: float = 0.0
    angular_z: float = 0.0


class DriveModeRequest(BaseModel):
    """ブラウザから受け取る運転モード切替要求（manual / auto / stop）。"""

    mode: str


class JetsonDetection(BaseModel):
    """Jetson の物体検出 1 件。box は画像に対する正規化座標 [x_min, y_min, x_max, y_max]。"""

    label: str
    prompt: str = ''
    score: float
    box: list[float]


class JetsonDetectionsRequest(BaseModel):
    """Jetson（NanoOWL など）から受け取るカメラ画像 1 枚分の検出結果。"""

    detections: list[JetsonDetection] = []
    model: str = ''
    inference_ms: float | None = None


class JetsonStatusRequest(BaseModel):
    """Jetson（jetson/status_reporter）から受け取る温度・使用率・メモリ・電力・AI の部品・更新の状況。"""

    hostname: str = ''
    os: str = ''
    l4t: str = ''
    power_mode: str = ''
    uptime_s: float | None = None
    cpu_percent: float | None = None
    cpu_freq_mhz: float | None = None
    gpu_percent: float | None = None
    gpu_freq_mhz: float | None = None
    temperatures_c: dict[str, float] = {}
    mem_total_mb: float | None = None
    mem_used_mb: float | None = None
    mem_available_mb: float | None = None
    swap_total_mb: float | None = None
    swap_used_mb: float | None = None
    input_volt: float | None = None
    power_w: float | None = None
    fan_percent: float | None = None
    fan_rpm: float | None = None
    disk_total_gb: float | None = None
    disk_used_gb: float | None = None
    services: dict[str, bool] = {}
    llm_models: list[str] = []
    stt_engine: str = ''
    tts_engine: str = ''
    llm_size_mb: float | None = None
    llm_vram_mb: float | None = None
    updates_pending: int | None = None
    updates_held: int | None = None
    security_pending: int | None = None
    reboot_required: bool | None = None
    last_upgrade: float | None = None
    ips: list[dict[str, str]] = []
    can_reboot: bool | None = None
    can_poweroff: bool | None = None
    can_upgrade: bool | None = None
    upgrade_running: bool | None = None
    upgrade_result: str = ''
    upgrade_percent: int | None = None
    upgrade_phase: str = ''


class MyPCStatusRequest(JetsonStatusRequest):
    """パソコン（jetson/stackchan_bridge/pc/pc_status.py）から受け取る状態。Jetson と同じ形に GPU の名前を足す。"""

    gpu_name: str = ''
    gpu_driver: str = ''
    ubuntu_updates_pending: int | None = None
    ubuntu_security_pending: int | None = None
    win_updates_pending: int | None = None
    win_security_pending: int | None = None
    win_reboot_required: bool | None = None


def host_status(req: JetsonStatusRequest):
    """Jetson・パソコンから届いた状態の、文字の長さと項目の数を絞る。"""
    status = req.model_dump()
    for key, value in status.items():
        if isinstance(value, str):
            status[key] = value[:64]
    status['temperatures_c'] = {k[:16]: round(v, 1)
                                for k, v in list(req.temperatures_c.items())[:8]}
    status['services'] = {k[:16]: v for k, v in list(req.services.items())[:8]}
    status['llm_models'] = [m[:64] for m in req.llm_models[:4]]
    status['ips'] = [{'iface': str(ip.get('iface', ''))[:16], 'addr': str(ip.get('addr', ''))[:64]}
                     for ip in req.ips[:8]]
    return status


JETSON_STATUS_TIMEOUT = 5.0
MYPC_ACTIONS = ('reboot', 'upgrade')
JETSON_REBOOT_WINDOW = 10.0
PI_REBOOT_DELAY = 10.0
STACKCHAN_BRIDGE_PORT = 8003
STACKCHAN_TIMEOUT = 2.0
STACKCHAN_PHOTO_TIMEOUT = 20.0
REBOOT_CMD = ['sudo', '-n', '/usr/bin/systemctl', 'reboot']
POWEROFF_CMD = ['sudo', '-n', '/usr/bin/systemctl', 'poweroff']
UPGRADE_CMD = ['sudo', '-n', '/usr/bin/systemctl', 'start', '--no-block', 'ai-car-upgrade.service']


def _can_sudo(cmd):
    """sudoers でパスワードなしに cmd を実行できるか（sudo -n -l の NOPASSWD の行で見る）。"""
    try:
        out = subprocess.run(['sudo', '-n', '-l'], capture_output=True, text=True,
                             timeout=5, check=False).stdout
    except (OSError, subprocess.TimeoutExpired):
        return False
    want = ' '.join(cmd[2:])
    return any('NOPASSWD:' in line and line.rstrip().endswith(want) for line in out.splitlines())


def _jpeg_dimensions(data: bytes):
    """JPEG のフレームヘッダ（SOFn）から (幅, 高さ) を読む。取れなければ None。"""
    i = 2
    end = len(data)
    while i + 9 < end:
        if data[i] != 0xFF:
            i += 1
            continue
        marker = data[i + 1]
        if 0xC0 <= marker <= 0xCF and marker not in (0xC4, 0xC8, 0xCC):
            height = int.from_bytes(data[i + 5:i + 7], 'big')
            width = int.from_bytes(data[i + 7:i + 9], 'big')
            return width, height
        if marker in (0xD8, 0x01) or 0xD0 <= marker <= 0xD7:
            i += 2
            continue
        i += 2 + int.from_bytes(data[i + 2:i + 4], 'big')
    return None


def _occupancy_table():
    """OccupancyGrid の値（int8 を符号なしで見たもの）→ 灰色の濃さ。不明 205、空き 254、占有 0。"""
    table = bytearray(256)
    for u in range(256):
        table[u] = 205 if u > 100 else 254 - round(u * 254 / 100)
    return bytes(table)


OCCUPANCY_TABLE = _occupancy_table()
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

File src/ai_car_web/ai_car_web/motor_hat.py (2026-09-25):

"""Adafruit Motor HAT のモーター端子（M1〜M4）と車輪位置の割り付け読み込み。

`motor_hat.yaml` の割り付けに端子ごとの固定情報（PCA9685 チャンネル・TB6612 の
ブリッジ）を重ねてダッシュボードとモーター制御ノードへ返す。
"""

import os

import yaml

from ai_car_web.gpio_pinout import _HEADER

# 物理ピン -> (名称, BCM, 種別)
_PINS = {pin: (name, bcm, kind) for pin, name, bcm, kind in _HEADER}

# 端子名 -> (PCA9685 PWM ch, IN1 ch, IN2 ch, TB6612 ブリッジ)
_CHANNELS = {
    'M1': (8, 10, 9, 'TB6612 #1 A'),
    'M2': (13, 11, 12, 'TB6612 #1 B'),
    'M3': (2, 4, 3, 'TB6612 #2 A'),
    'M4': (7, 5, 6, 'TB6612 #2 B'),
}

# 車輪位置 -> (表示名, 機体座標 x 前+, y 左+)
WHEELS = {
    'front_left': ('前左', 1, 1),
    'front_right': ('前右', 1, -1),
    'rear_left': ('後左', -1, 1),
    'rear_right': ('後右', -1, -1),
}


def _encoder_pin(pin, label, seen, warnings):
    """エンコーダー信号ピンを検証し {pin, bcm, name} を返す（未設定なら None）。"""
    if pin is None:
        return None
    info = _PINS.get(pin)
    if info is None or info[1] is None:
        warnings.append(f'{label}: 物理ピン {pin} は GPIO ではありません')
        return {'pin': pin, 'bcm': None, 'name': info[0] if info else ''}
    if info[2] in ('i2c', 'id'):
        warnings.append(f'{label}: ピン {pin} ({info[0]}) は I2C/ID 用です')
    if pin in seen:
        warnings.append(f'{label}: ピン {pin} が {seen[pin]} と重複しています')
    seen[pin] = label
    return {'pin': pin, 'bcm': info[1], 'name': info[0]}


def _power_pin(pin, label, kind, warnings):
    """エンコーダー電源ピン（3V3 / GND）を検証し {pin, bcm, name} を返す。"""
    if pin is None:
        warnings.append(f'{label}: ピンが未設定です')
        return None
    info = _PINS.get(pin)
    if info is None:
        warnings.append(f'{label}: 物理ピン {pin} は存在しません')
        return {'pin': pin, 'bcm': None, 'name': ''}
    if info[2] != kind:
        expect = '3V3' if kind == 'power3v3' else 'GND'
        warnings.append(f'{label}: ピン {pin} ({info[0]}) は {expect} ではありません')
    return {'pin': pin, 'bcm': info[1], 'name': info[0]}


def _pin_text(p, board='Pi'):
    if not p:
        return '-'
    detail = f'GPIO{p["bcm"]}' if p['bcm'] is not None else p['name']
    return f'{board} pin {p["pin"]} ({detail})'


def _power_text(p, board='Pi'):
    if not p:
        return '-'
    return f'{board} ({p["name"]})' if board != 'Pi' else _pin_text(p, board)


def load_motor_hat(path):
    """割り付け YAML を読み、ダッシュボード表示用の辞書を返す。"""
    if not path or not os.path.exists(path):
        error = f'{path} が見つかりません' if path else '割り付け設定ファイル未指定'
        return {'config_path': path, 'error': error, 'hat': {}, 'motors': [], 'warnings': []}
    with open(path, encoding='utf-8') as f:
        data = yaml.safe_load(f) or {}

    hat = dict(data.get('hat') or {})
    addr = hat.get('i2c_address')
    if isinstance(addr, int):
        hat['i2c_address'] = f'0x{addr:02X}'

    warnings = []
    motors = []
    seen_channels = set()
    seen_wheels = set()
    seen_pins = {}
    enc_common = dict(hat.get('encoder') or {})
    enc_common['colors'] = [str(c) for c in enc_common.get('colors') or [] if c]
    hat['encoder'] = enc_common
    # VCC / GND の接続先ボード。Motor HAT は Pi の 40 ピンを引き出しているので
    # HAT 上の 3V3 / GND ピンを使う場合は power_board を 'Motor HAT' にする（ピン番号は共通）。
    power_board = str(enc_common.get('power_board') or 'Pi')
    for entry in data.get('motors') or []:
        channel = str(entry.get('channel') or '').upper()
        wheel = str(entry.get('wheel') or '')
        if channel not in _CHANNELS:
            warnings.append(f'不明な端子名: {channel or "(空)"}')
            continue
        if wheel not in WHEELS:
            warnings.append(f'{channel}: 不明な車輪位置 {wheel or "(空)"}')
        if channel in seen_channels:
            warnings.append(f'{channel} が重複しています')
        if wheel in seen_wheels:
            warnings.append(f'{wheel} に複数の端子が割り付けられています')
        seen_channels.add(channel)
        seen_wheels.add(wheel)
        pwm, in1, in2, bridge = _CHANNELS[channel]
        label, x, y = WHEELS.get(wheel, ('', 0, 0))
        colors = entry.get('colors') or []
        colors = [str(c) for c in colors if c]
        enc = entry.get('encoder') or {}
        encoder = None
        tag = f'{channel} {label}'.strip()
        if enc:
            ecol = [str(c) for c in enc.get('colors') or [] if c] or enc_common['colors']
            ecol = (ecol + [''] * 4)[:4]
            vcc_pin = enc.get('vcc_pin', enc_common.get('vcc_pin'))
            encoder = {
                'vcc': _power_pin(vcc_pin, f'{tag} VCC', 'power3v3', warnings),
                'gnd': _power_pin(enc.get('gnd_pin'), f'{tag} GND', 'ground', warnings),
                'a': _encoder_pin(enc.get('a_pin'), f'{tag} Encoder A', seen_pins, warnings),
                'b': _encoder_pin(enc.get('b_pin'), f'{tag} Encoder B', seen_pins, warnings),
                'colors': ecol,
            }
        # 1 モーター 6 本の線をすべて列挙（表示・配線作業用）
        mcol = (colors + [''] * 2)[:2]
        wires = [
            {'name': 'Motor+', 'color': mcol[0], 'dest': f'Motor HAT {channel} +',
             'note': 'モーター +（基板印字 M+）'},
            {'name': 'Motor−', 'color': mcol[1], 'dest': f'Motor HAT {channel} −',
             'note': 'モーター −（基板印字 M−）'},
        ]
        if encoder:
            vcc = enc_common.get('vcc') or ''
            wires += [
                {'name': 'VCC', 'color': ecol[0],
                 'dest': _power_text(encoder['vcc'], power_board),
                 'note': f'エンコーダー電源 {vcc}（基板印字 VCC）'},
                {'name': 'GND', 'color': ecol[1],
                 'dest': _power_text(encoder['gnd'], power_board),
                 'note': 'エンコーダー GND（基板印字 GND）'},
                {'name': 'Encoder A', 'color': ecol[2], 'dest': _pin_text(encoder['a']),
                 'note': 'エンコーダー A 相（基板印字 S1）'},
                {'name': 'Encoder B', 'color': ecol[3], 'dest': _pin_text(encoder['b']),
                 'note': 'エンコーダー B 相（基板印字 S2）'},
            ]
        else:
            warnings.append(f'{tag}: encoder が未設定（6 本中 4 本が未割り付け）')
        motors.append({
            'channel': channel,
            'wheel': wheel,
            'wheel_label': label,
            'position': {'x': x, 'y': y},
            'reversed': bool(entry.get('reversed', False)),
            'colors': colors,
            'label': tag,
            'note': entry.get('note') or '',
            'pwm_channel': pwm,
            'in1_channel': in1,
            'in2_channel': in2,
            'bridge': bridge,
            'encoder': encoder,
            'wires': wires,
        })
    for wheel in WHEELS:
        if wheel not in seen_wheels:
            warnings.append(f'{WHEELS[wheel][0]}（{wheel}）に端子が割り付けられていません')

    return {
        'config_path': path,
        'error': None,
        'hat': hat,
        'motors': motors,
        'warnings': warnings,
    }

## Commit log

2026-09-12 AT-CAR ワークスペース初期コミット: ai_car_description と ai_car_web を追加
    [ai_car.xacro]
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2026-09-13 表記修正: AT-CAR を AI-CAR に統一
    [dashboard_node.py]
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2026-09-14 カメラカードに解像度・実測fps・1枚あたりサイズを表示し、検出枠のアスペクトずれを修正
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2026-09-14 docs: AE Short モード化を変更履歴に追記
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2026-09-15 ダッシュボードに Motor HAT 接続図カードを追加（M1〜M4 と車輪位置の割り付け）
    [motor_hat.yaml]
2026-09-15 520 モーターエンコーダーの Pi GPIO 割り付けを追加し接続図・GPIO 表に表示
    [motor_hat.yaml]
2026-09-15 520 モーターの配線色を資料どおりに修正し、表記を「M1 前左 Motor+」形式に統一
    [motor_hat.yaml]
2026-09-15 Motor HAT 接続図・一覧表で 1 モーター 6 本（Motor+/Motor−/VCC/GND/Encoder A/B）をすべて明示
    [motor_hat.yaml]
2026-09-15 エンコーダー VCC / GND を Motor HAT 上の 3V3 / GND ピンへ接続する表記に変更
    [motor_hat.yaml]
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2026-09-18 drive_mode: 安全停止とダッシュボード認証を修正
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2026-09-18 dashboard: プロジェクト説明の renderAutonomy がテレメトリ描画関数を上書きしていた問題を修正
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2026-09-23 配線: モーター 6 本の配線色を実物ケーブルに合わせて修正（Motor− 黒 / VCC 橙 / GND 白 / A 黄 / B 緑）
    [motor_hat.yaml]
2026-09-23 モーター配線色をエンコーダー基板印字に基づき確定（Motor+ 緑 / Motor− 橙 / VCC 黄 / GND 白 / A 赤 / B 黒）
    [motor_hat.yaml]
2026-09-23 motor_hat.yaml: HAT 電源端子の配線色（赤 / 黒）を元に戻す
    [motor_hat.yaml]
2026-09-23 モーター 6 本の配線色を端子基板の印字どおりに修正（Motor+ 黒 / Motor− 赤 / VCC 白 / GND 黄 / A 橙 / B 緑）
    [motor_hat.yaml]
2026-09-24 エンコーダー VCC / GND をテスター実測に合わせ VCC 黄 / GND 白 に修正
    [motor_hat.yaml]
2026-09-24 モーター配線の VCC / GND を基板コネクタ印字どおり白 / 黄に戻す
    [motor_hat.yaml]
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2026-09-25 エンコーダー VCC / GND の接続先表記を Motor HAT (3V3 power) / Motor HAT (Ground) に統一
    [motor_hat.yaml]
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2026-09-25 バッテリー 2 個 + RPLIDAR A1M8 の 3D プリントマウントを追加
    [battery_lidar_mount.scad, box.stl, lid.stl]
2026-09-25 ラズパイ台とカメラ取付を追加
    [battery_lidar_mount.scad, box.stl, lid.stl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]
2026-09-25 ラズパイ 3 段（45 mm）の高さを反映し、横から見た図を追加
    [battery_lidar_mount.scad]
2026-09-25 ラズパイ台に IMU（GY-BNO055）の受けと液晶（ZJY-IPS130）のスタンドを追加
    [battery_lidar_mount.scad, pi_base.stl]
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2026-09-25 バンパーのばねを板ばねに変更し、ストッパーで 4 mm 以内に止まるよう寸法を見直し
    [battery_lidar_mount.scad, bumper.stl]
2026-09-25 ネジ穴を用途別の形に（ねじ込み下穴 / インサート切替、LiDAR は座ぐり付き通し穴）
    [battery_lidar_mount.scad, box.stl, lid.stl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]
2026-09-25 配線経路を確認して修正（カメラのフラットケーブルを LiDAR のモーター下から右側へ、結束バンド用ブリッジ、モーター線の開口、配線表）
    [battery_lidar_mount.scad, box.stl, lid.stl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]
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2026-09-25 DROK 降圧コンバーターの受けを箱の後ろの壁に追加（結束バンド固定、12V 入力と USB-A 出力の配線経路）
    [battery_lidar_mount.scad, box.stl]
2026-09-25 ダッシュボードのデバイス一覧に VL53L1X・DROK・CIO バッテリーを追加し、IMU と液晶の表示名を修正
    [architecture.yaml]
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2026-09-25 加速度センサーの受けをピン下向き用の高さ 25 mm の台に変更し、液晶の前へ移動
    [battery_lidar_mount.scad, pi_base.stl]
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2026-09-26 液晶の枠の底を台まで埋め、IMU の台を 12×20 mm の壁付き（Pi 側にケーブル穴）に変更。カバーとバンパーの手で触る縁を 1 mm 面取り
    [battery_lidar_mount.scad, bumper.stl, cover.stl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]
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2026-09-26 落下防止センサーの傾きを 30° から 45° に変更し、受けを 4.5 mm 前へ出す
    [battery_lidar_mount.scad, bumper.stl]
2026-09-26 天板の厚さを実測の 2 mm にし、カバーのフックの掛かり面を合わせる
    [battery_lidar_mount.scad, cover.stl]
2026-09-26 PLA で印刷できるよう、バンパーの板ばねを 0.8 mm にし材料の説明を PLA に合わせる
    [battery_lidar_mount.scad, bumper.stl]
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2026-09-26 箱の開口側のボス 2 本を欠けのない円柱に戻し、バッテリーは上から出し入れすると説明を修正
    [battery_lidar_mount.scad, box.stl]
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2026-09-26 PDF の組み立て図・配線経路の画像が空白になるのを修正
2026-09-26 バッテリー箱の内寸を実測に合わせ、前後のすき間を片側 0.4 mm にする
    [battery_lidar_mount.scad, box.stl, cover.stl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]
2026-09-26 液晶スタンドの溝の幅を 0.6 mm 広げ、ピンヘッダーが台に当たらないよう溝の底を 10 mm 上げる
    [battery_lidar_mount.scad, pi_base.stl]
2026-09-27 加速度センサーの台を Pi の右側（USB・LAN の側）へ移し、ピンヘッダーの長辺を開けた 3 辺の溝で固定する
    [battery_lidar_mount.scad, pi_base.stl]
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2026-09-27 Pi 5 のボスを 2 mm 右へ移し、液晶スタンドとのすき間を 2.65 mm にする（IMU の台も 2 mm 右へ）
    [battery_lidar_mount.scad, pi_base.stl]
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2026-09-27 IMU の台の短い方向をピンヘッダーの列の幅 2.56 mm 分短くする
    [battery_lidar_mount.scad, pi_base.stl]
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2026-09-27 ラズパイ台の Pi 5 の受けを、M2.5 六角支柱を差し込んで裏からネジで留める丸い穴にする
    [battery_lidar_mount.scad, pi_base.stl]
2026-09-27 バッテリーの長手方向のすき間を確かめる 2 mm のプレート（bat_shim.stl）を追加
    [bat_shim.stl, battery_lidar_mount.scad]
2026-09-27 バッテリー箱の開口と反対側の端の壁を内側へ 2 mm 厚くし、確認用プレートをなくす
    [bat_shim.stl, battery_lidar_mount.scad, box.stl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]
2026-09-27 IMU の台の奥の長辺に、基板を上から押さえる 3 mm x 厚さ 3 mm の出っ張りを付ける
    [battery_lidar_mount.scad, pi_base.stl]
2026-09-28 カバーの STL を鏡像でなく回転で上下反転し、フックを前後の端から 30 mm へ移動（右前は固定の爪）、受けをフックの両隣に置き直す
    [battery_lidar_mount.scad, cover.stl]
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2026-09-29 上面カバーを 20 mm 高くする（cov_top 60 → 80 mm、cover.stl の高さ 87.9 mm）
    [battery_lidar_mount.scad, cover.stl]
2026-09-29 LiDAR の取付柱を 28 → 48 mm にして、ヘッドをカバーの上面より上に出す
    [battery_lidar_mount.scad, lid.stl]
2026-09-29 カメラの板のネジ穴 4 か所を M2.5 が貫通する通し穴にし、ナットがリブに当たらないよう板を 32 mm 幅に
    [battery_lidar_mount.scad, cover.stl, lid.stl]
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2026-09-29 車体を載せて車輪を浮かせる試験台を追加（4 隅受け、床から 80 mm、すき間 1 mm）
    [test_stand.scad, test_stand.stl]
2026-09-29 試験台を床板 10 mm（中抜きの斜め格子）でつないだ 1 個にし、3D プリントタブに部品と試験台付きの組み立て図を追加
    [test_stand.scad, test_stand.stl]
2026-09-29 試験台の車輪・車軸の寸法を OSOYOO の図面の値にし（直径 80.59 mm、車軸 52 mm）、受け面を 40 mm に広げて 4 隅の穴の下にナットよけのくぼみを付ける
    [test_stand.scad, test_stand.stl]
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2026-09-29 ダッシュボードの Raspberry Pi 5 — CPU カードにメモリと Swap 使用率を追加
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2026-10-01 カメラと LiDAR の位置の差の補正: 距離もカメラから前方の距離にし、方位をピンホールの式に。URDF の laser / camera_link を CAD の位置に
    [ai_car.xacro]
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2026-10-01 LiDAR の前方を実測値 -1.7° で前方カメラの正面に固定し、前方合わせボタンを削除。表示範囲を 3 m に固定
    [ai_car.xacro]
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2026-10-02 3D プリント部品: Pi カメラと液晶をなくし、2 眼カメラの受けと LiDAR の下の IMU の台を追加
    [ai_car.xacro, battery_lidar_mount.scad, cam_cap.stl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]
2026-10-02 2 眼カメラを実測に合わせ、USB 端子を上にして四隅の M2 で板に留める形に変更。カバーの窓をレンズごとに分ける
    [ai_car.xacro, battery_lidar_mount.scad, cam_cap.stl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]
2026-10-02 3D: Pi 5 を左へ寄せ、カバーの左に電源ボタンの穴、右の USB 側を広げる
    [battery_lidar_mount.scad, cover.stl, pi_base.stl]
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2026-10-03 3D: ふたのカメラの柱の M3 を貫通・M2 ナットの逃げを追加、IMU の台を後ろの柱の間へ移す
    [battery_lidar_mount.scad, lid.stl]
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2026-10-04 3D: 2 眼カメラの板の四隅の M2 の下穴を Ø2.5 にする
    [battery_lidar_mount.scad, cam_mount.stl]
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2026-10-04 3D: バッテリー箱のボスの上の部分を上 5 mm の中だけの三角の板にする
    [battery_lidar_mount.scad, box.stl]
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2026-10-06 3D: Camera Module 3 Wide (SC0874) 用のカメラの板とカバーの窓、フラットケーブルの経路
    [battery_lidar_mount.scad, cam_mount.stl, cam_mount_stereo.stl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]
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2026-10-07 3D: Camera Module 3 Wide の板の裏に M2 ナットのくぼみ、ふた・箱の前の面にナットとネジの先の逃げ穴
    [battery_lidar_mount.scad, box.stl, cam_mount.stl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]
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2026-10-08 前方カメラを Camera Module 3 Wide（camera_ros）に戻す
    [ai_car.xacro]
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2026-10-17 dashboard: SLAM の地図に「地図をクリア」ボタン（slam_toolbox の reset）
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2026-10-24 3D: replace USB switch holder with CC switch box (cc_holder), cover slots (v1.29.8)
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2026-10-28 fix(jetson): scpのCRLF対策手順とJetson版表示フォールバック
    Windowsミラー由来scpでCRLFがbashを壊しJetsonテストスナップショットが失敗したため、CR除去と構文確認を反映手順に明文化。旧manifestではjetson_versionが無く一覧が版なし表示になるためL4T REVISIONフォールバックを足した。
2026-10-28 fix(dashboard): Jetson旧manifestの版表示をv36.4.7表記に
    REVISION抽出が4.7だけ返してUIでv4.7となりL4T全体名と食い違ったため、36.接頭辞を足してv36.4.7統一表示にした。
2026-10-28 fix(dashboard): バックアップカードのラズパイ/Jetson系統をラベルで明示
    Pi側の行が無表記で、Jetsonセクションと並んだときどちらの系統か読みにくかったため、ラズパイ表記を各行とバッジに明記。題名に2系統注記。
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2026-10-28 fix: API認証で非ASCIIトークンヘッダーを401で返す（compare_digest TypeErrorによる500回避）
    PR #342のJetson復元発動テストで検出。あわせてJetson復元E2E実測成功（sudoers導入済み、sudo -n /usr/local/bin/ai-jetson-restore jetson-20261029_054354-v36.4.7 → 復元完了 exit 0、全jetson-*サービスactive）。Piフック ai-car-20261029_060233 sha c31c991f499a（PCミラー照合済み）。
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2026-10-29 fix(stackchan): 電源行のカンマ欠落を修正（v1.32.3）
2026-10-30 fix(restore): ダッシュボード停止で復元スクリプトが殺されるのを修正・root側で名前検証（v1.32.4）
2026-10-30 fix(restore): Devin指摘対応 cgroup移動直後に trap '' INT TERM HUP（sudo経由の途中終了防止）
2026-10-30 fix(dashboard): 復元ボタンに確認と二重押し防止を追加（v1.32.5）
2026-10-30 fix(dashboard): Devin指摘対応 restore_startedの判定と記録をthreading.Lockで保護
2026-10-30 fix(jetson): 復元スクリプトの名前検証・manifest argv化・稼働中サービスだけrestart（v1.32.6）
2026-10-30 fix(jetson): Devin指摘対応 restartに|| echo追加（set -eで復元後半が止まらないように）
2026-10-30 fix(dashboard): バックアップ一覧の名前・版をエスケープ表示（v1.32.7）
2026-10-30 docs: PROJECT_STATUS整合修正（バージョン行1.32.6→1.32.8・更新日・PR#343〜#350項目の追記順復帰）
2026-10-30 fix(jetson-restore): 復元後は声のLLMを先に載せてから jetson-* を起動（v1.32.9）
2026-10-30 fix(jetson-restore): 復元の最後は Jetson ごと再起動（サービス1つずつだと GPU メモリ不足）
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2026-11-01 fix(stackchan): パソコンの VOICEVOX（CPU）の声と声ごとの話し方は残す
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2026-11-01 fix: 声を変えたらすぐ表示に出す・VOICEVOX のときは文字→声の欄に VOICEVOX を出す
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2026-11-03 fix(3d): リポの台の床を 11 mm に上げてネジの頭を逃がし、面ファスナーを床の下に通す。ふたの右後ろのネジを LiDAR の柱から離す
2026-11-03 fix(3d): リポの台の前の縁をなくし、リポを前から IMU の橋の下へ差し込めるようにする
2026-11-03 fix(3d): リポの形のふたの右前のネジを 4 mm 後ろへ（カメラの耳の柱に頭が当たる、v2.0.5）
2026-11-03 fix(3d): リポの形の右のネジの柱を前後の壁まで板でつなぐ
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2026-11-03 fix(3d): ぶつかりチェックで、許した組の上限・空の部品・OpenSCAD の ERROR を失敗にする
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2026-11-05 fix(lidar): C1 の実機確認（/scan 10 Hz）を記録、package.xml の BOM を取る
2026-11-05 fix(lidar): C1 の向きを実測して scan_angle_offset_deg / laser_yaw_deg を −176.2° に
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2026-11-05 fix(cliff): 床の補正ボタンを左に出して、結果は短く（全文はマウスを乗せる）
2026-11-05 fix(dashboard): Jetson のカードのミニコン／パソコン切りかえボタンを削除（v2.2.1）
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2026-11-05 fix(dashboard): バックアップのグラフの時刻に秒を出し、表の順（色）を機械ごとに固定
2026-11-05 fix(dashboard): Jetson につながらないときは「見えない」にし、root の照合のあとにできた manifest で「終わった」にする
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2026-11-05 fix(backup): ミラーの名前を英数字・._- だけにし、manifest は照合が合ってから PC に置く
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2026-11-05 fix(backup): Jetson のバックアップから変わらない open-webui-backup-0.6.14 を外す（v2.7.1）
2026-11-05 fix(backup): 動画の rsync が失敗したら NG にする（tee の終了値を見ていた）
2026-11-05 docs(backup): 古いバックアップを戻したあとは git checkout ではなく git reset <コミット>
2026-11-05 fix(dashboard): バックアップ中の様子の終わった仕事は機械ごとに 1 件、各行にバージョン（v2.7.2）
2026-11-05 fix(dashboard): バックアップ中の様子のグラフを表の上へ
2026-11-05 fix(dashboard): 同じときに終わった仕事は、あとで始まったほうを残す
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2026-11-05 fix(backup): ai-backup-mirror.sh は同じ機械で 1 つだけ（flock）
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
